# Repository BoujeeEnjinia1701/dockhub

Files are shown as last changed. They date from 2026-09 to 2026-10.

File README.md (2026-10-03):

# DockHub

     

**Area:** Smart Cities · **TRL:** 3 of 9 (proof of concept on paper) · **Value-engineering target:** about $1,200 USD (four-bay cabinet, two bays fitted) · **Difficulty:** 4 of 5

A street-side battery swap and charging station for SwapCell packs, serving e-bikes, cargo trikes and delivery riders with charged batteries in seconds.

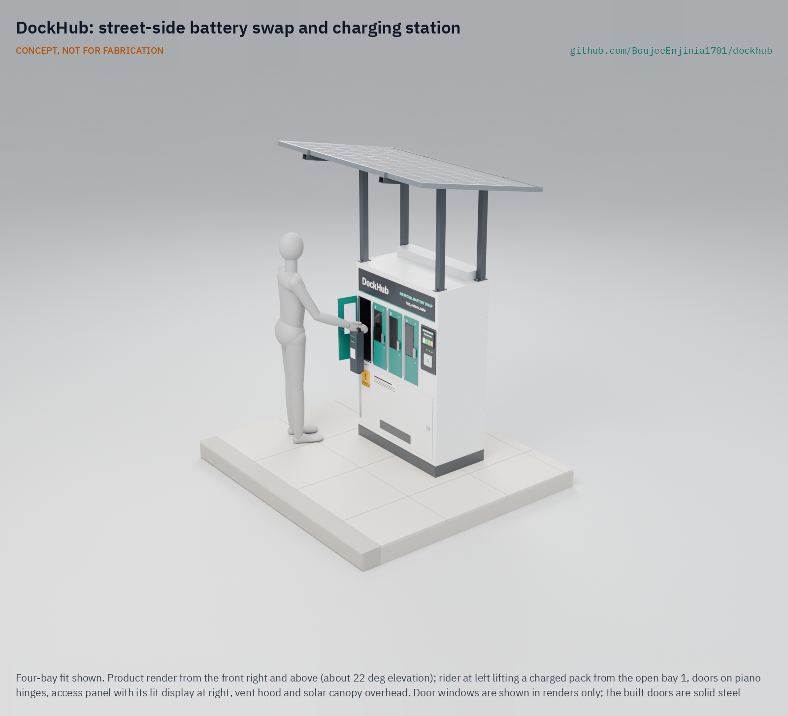
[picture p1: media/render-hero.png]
DockHub: street-side battery swap and charging station, product render


[Exploded render](media/render-exploded.png) · [Detail render](media/render-detail.png) · [Interactive 3D model](media/viewer.html) · [Concept blueprint (PDF)](media/concept-blueprint.pdf) · [General arrangement DKH-DWG-001 (PDF)](cad/drawings/DKH-DWG-001.pdf) · [Sizing note](docs/04-calcs/01-sizing.md) · [Prototype build plan](docs/05-build-plan.md) · [Design decisions](docs/06-design-decisions.md) · [Review note](docs/REVIEW.md)

## Concept rationale

Swapping moves charging out of homes and into a monitored steel cabinet, and turns hours at a socket into about 30 seconds at the curb. DockHub does this by putting four copies of the SwapCell wall dock into one sidewalk cabinet: each bay has its own cradle, certified charger and CAN check, and its own steel compartment that vents to the back and up, away from the rider. The cabinet adds only what a public site needs: access control, fire detection, a single-phase grid supply and a solar canopy that also shades the front.

It is open and garage-buildable because closed swap networks tie riders and small fleets to one operator's batteries. DockHub is folded sheet steel, off-the-shelf certified chargers and an ESP32, built to the open SwapCell interface, so a city, a rider cooperative or a courier firm can build, repair and inspect its own station and use packs from any SwapCell-compatible source.

## Burning platform

Most lithium battery fires in light vehicles start during charging, and much of that charging happens where people sleep. The US Consumer Product Safety Commission counted 227 micromobility battery incidents from 2019 to 2023, associated with 39 deaths and 181 injuries; 120 of them happened while charging ([Federal Register, 24 June 2026](https://www.federalregister.gov/documents/2026/06/24/2026-12749/safety-standard-for-lithium-ion-batteries-used-in-micromobility-products-and-electrical-systems-of)). New York City had 277 lithium-ion battery fires in 2024 ([FDNY](https://www.nyc.gov/site/fdny/news/03-25/fdny-commissioner-robert-s-tucker-significant-progress-the-battle-against-lithium-ion)), and London Fire Brigade attended a record 206 e-bike and e-scooter fires in 2025, an average of one every other day ([London Fire Brigade](https://www.london-fire.gov.uk/news/2026-news/january/record-number-of-e-bike-and-e-scooter-fires-across-london-in-2025-as-brigade-calls-for-regulation-to-be-introdu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)).

At the same time, the number of electric two- and three-wheelers keeps growing: India sold about 880,000 electric two-wheelers and more than 580,000 electric three-wheelers in 2023 ([IEA, Global EV Outlook 2024](https://www.iea.org/reports/global-ev-outlook-2024/trends-in-other-light-duty-electric-vehicles)). India's draft swapping policy notes that charging these vehicles "takes at least 3 to 4 hours" while a swap takes minutes ([NITI Aayog, 2022](https://www.niti.gov.in/sites/default/files/2022-04/20220420_Battery_Swapping_Policy_Draft_0.pdf)). For people paid per delivery or per trip, that time is lost income.

## Where it could be used

### By industry

| Industry | Use |
| --- | --- |
| App-based food and parcel delivery | Curbside swaps near restaurant clusters so riders never charge at home |
| Courier and cargo-bike logistics | Depot or loading-zone station for cargo trikes sharing one pack pool |
| Moto-taxi and informal transport | Swaps at taxi ranks and markets for light electric two- and three-wheelers |
| Shared micromobility | Battery exchange for shared e-bike and scooter fleets without vans collecting vehicles |
| Property and retail hosts | A safe charging offer for tenants or staff, instead of packs in corridors |
| Municipal fleets | Parks, parking and postal staff on e-bikes and cargo trikes |

### By country or region

| Country or region | Why it matters there |
| --- | --- |
| United States (New York City) | 268 lithium-ion battery fires and 18 deaths in 2023, 277 fires in 2024 ([FDNY](https://www.nyc.gov/site/fdny/news/03-25/fdny-commissioner-robert-s-tucker-significant-progress-the-battle-against-lithium-ion)); swap hubs for delivery workers already operate there ([Swobbee](https://www.swobbee.com/)) |
| United Kingdom (London) | Record 206 e-bike and e-scooter fires in 2025; every person killed in these fires since 2023 did not own the e-bike involved ([London Fire Brigade](https://www.london-fire.gov.uk/news/2026-news/january/record-number-of-e-bike-and-e-scooter-fires-across-london-in-2025-as-brigade-calls-for-regulation-to-be-introdu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)) |
| Australia (New South Wales) | 272 lithium-ion battery fires and 38 injuries in 2023, about five a week ([Fire and Rescue NSW](https://www.fire.nsw.gov.au/media/news/2024/20240315-fire-and-rescue-nsw-recording-lithium-ion-battery-fires-at-a-rate-of-five-a-week)) |
| India | The largest electric three-wheeler market, with more than 580,000 sold in 2023 ([IEA](https://www.iea.org/reports/global-ev-outlook-2024/trends-in-other-light-duty-electric-vehicles)); national policy favors interoperable swapping ([NITI Aayog](https://www.niti.gov.in/sites/default/files/2022-04/20220420_Battery_Swapping_Policy_Draft_0.pdf)) |
| East Africa (Rwanda and Kenya) | Moto-taxi swapping already runs at scale, with more than 20,000 swaps a day on one closed network ([Ampersand](https://www.ampersand.energy/)); an open station could serve smaller operators |
| Southeast Asia (Vietnam) | About 250,000 electric two-wheelers sold in 2023, most of the ASEAN total ([IEA](https://www.iea.org/reports/global-ev-outlook-2024/trends-in-other-light-duty-electric-vehicles)) |

## What sparked the idea

The starting point was New York City's public e-bike battery charging pilot. From February to August 2024 the city's Department of Transportation put swap cabinets and charging docks from three vendors on the street for 118 delivery workers, who made more than 12,000 battery swaps; at-home charging among participants fell by 35 percent, and no safety issues were reported at any pilot site ([NYC DOT, 21 November 2024](https://www.nyc.gov/html/dot/html/pr2024/report-e-bike-battery-change-pilot.shtml)). The pilot showed that a curbside cabinet can take charging out of homes. DockHub asks what the same cabinet looks like when it is built to an open pack interface (SwapCell), so that a city, a cooperative or a small fleet can build and run it without tying riders to one vendor's batteries.

## Problem

Light electric vehicle riders lose working time to charging, and charging lithium packs in homes and hostels causes fires. Commercial swap networks exist, but each one locks riders into its own batteries.

Full problem statement: [docs/01-problem.md](docs/01-problem.md)

## Concept

A street-side battery swap and charging station for SwapCell packs, serving e-bikes, cargo trikes and delivery riders with charged batteries in seconds. Four lockable bays at hand height each hold and charge one pack; a rider taps a card, returns a flat pack to the empty bay and takes a charged one in about 31 seconds. Because one bay is always empty, four bays run with three packs.

The TRL 3 sizing note (DKH-CAL-001) finds 1.2 h to charge a pack from 20 to 80 %, all 20 riders served on the design day (up to 36 swaps a day), 1.25 kW peak from one single-phase circuit with power-factor-corrected chargers, and a mass of about 217 kg for the two-bay prototype. The 400 W canopy supplies 9.3 % of the charging energy, and the SwapCell pack's 45 °C charge limit pauses charging when ambient air is above about 29 to 39 °C. Amish restated both targets on 2026-10-02: about 9 % solar, and full-rate charging up to about 30 °C ambient with daytime pauses accepted, so the first pilot goes where summer highs sit near that. The parts added to make the design buildable bring the estimated cost to $1,214, and the four M12 anchors and cast concrete pad chosen for the first pilot on private ground add $305, for $1,519 against the $1,200 value-engineering target. With the pad, the cabinet stays upright at a 30 m/s gust on paper; fire containment remains at risk.

Full design precis: [docs/02-concept.md](docs/02-concept.md) · Requirements: [docs/03-requirements.md](docs/03-requirements.md) · Calculations: [docs/04-calcs/01-sizing.md](docs/04-calcs/01-sizing.md) · Decisions: [docs/decisions/0001-trl2-review-decisions.md](docs/decisions/0001-trl2-review-decisions.md), [docs/decisions/0002-recommendations-accepted.md](docs/decisions/0002-recommendations-accepted.md), [docs/decisions/0003-design-for-construction.md](docs/decisions/0003-design-for-construction.md)

## Key components

- Galvanized steel cabinet, 1.0 x 0.5 m footprint, with four lockable SwapCell bays (interface v0.3) in separate steel compartments; the first prototype fits two
- Certified 54.6 V 5 A charger per bay with power factor correction, switched by the controller
- ESP32 dock controller with one CAN channel per bay and an LTE-M modem
- NFC access panel with display and status lights
- Heat and smoke detection, aerosol suppression and a rear vent plenum
- 400 W solar canopy with MPPT controller feeding bay 1, and a single-phase grid input with RCD protection
- Steel plinth held by four M12 wedge anchors to a 1,400 x 1,100 x 300 mm cast concrete pad; the canopy makes anchoring mandatory

The priced bill of materials is in [bom/bom.csv](bom/bom.csv). Value-engineering target for the four-bay cabinet with two bays fitted: $1,200 (a hypothetical control target, not a limit). Estimated cost of the constructable design: $1,519 ($319 over the target) on indicative prices, including $305 for the anchors and site pad; cost drivers and savings worth trying are in the [design decisions register](docs/06-design-decisions.md). All four bays fitted cost $1,743. A vermiculite bay floor tray is priced as a trial option for the propagation trial and is not in the total. SwapCell packs are not included. The parametric model is [cad/src/model.py](cad/src/model.py), with STEP and STL exports in `cad/step/` and `cad/stl/`.

## Building the prototype

The [prototype build plan](docs/05-build-plan.md) (DKH-BLD-001) shows how to make each of the cabinet's components and put them together in 22 steps, with a making sketch for every made part and a picture for every step. The cabinet is a shell of folded 1.5 mm galvanized panels joined with blind rivets on a welded channel plinth, with a roof frame of steel angle carrying the canopy posts. Making the concept buildable changed some details, such as the 150 mm door openings, the vent hood over the roof fans and the roof beams, all listed in [DKH-DDR-003](docs/decisions/0003-design-for-construction.md) for Amish's review. It is a plan: nothing has been built.

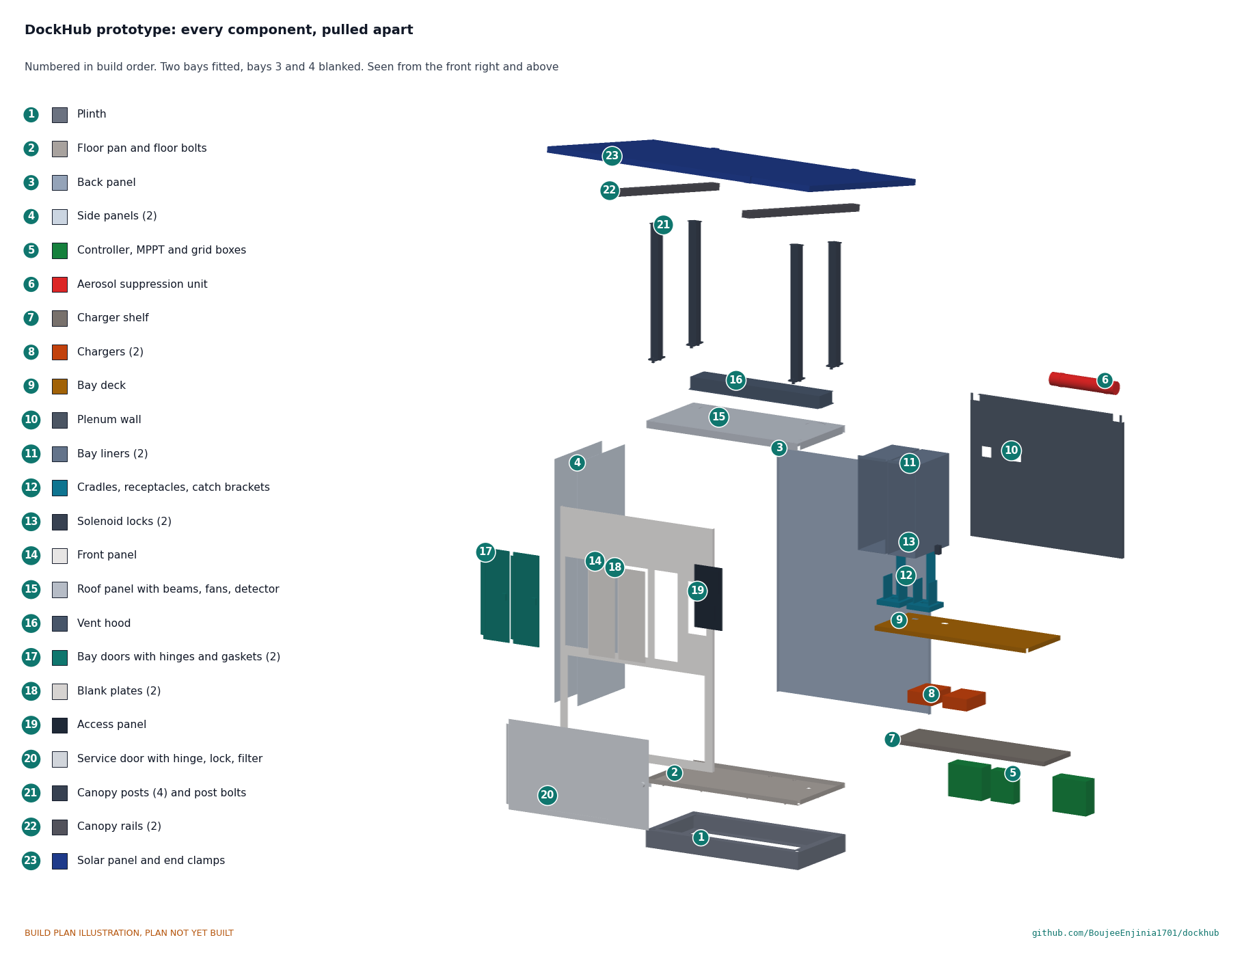
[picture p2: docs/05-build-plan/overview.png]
DockHub prototype: every component, pulled apart and numbered in build order


## Safety

> Lithium cells can overheat, vent and burn. DockHub holds up to four packs of about 468 Wh each beside a public walkway. Charge only packs that pass the SwapCell CAN check, keep faulted packs locked in their bay, and never leave a first build charging unattended. Mains wiring must be done or checked by a qualified electrician and follow local electrical code, with RCD (GFCI) protection. Fire detection and venting are in every bay, but fire containment is not yet proven. Anchor the cabinet to a concrete pad: in a 30 m/s gust the canopy lifts and tips it (DKH-CAL-001). Charging pauses in hot weather because the packs may not charge above 45 °C.

## Repository layout

| Folder | Contents |
| --- | --- |
| `docs/` | Problem, concept, requirements, calculations and design decisions |
| `cad/src/` | build123d Python source, the source of truth for all geometry |
| `cad/step/`, `cad/stl/` | Exported models for FreeCAD, other CAD tools and printing |
| `cad/drawings/` | 2D sketches and dimensioned drawings |
| `bom/` | Bill of materials |
| `electronics/` | KiCad schematics and PCB layouts |
| `firmware/` | Microcontroller code |
| `media/` | Renders, perspectives and photos |
| `build-log/` | Dated prototyping notes |

## Documentation

Controlled documents follow the portfolio [documentation standard](.kit/STANDARDS.md). Each carries a document ID (DKH-PRC-001 for the precis), a version and a revision history. Branded PDFs are built with `python .kit/render.py` and attached to GitHub Releases when a document is tagged, for example `DKH-PRC-001/v1.0`.

## Credits

Designed by Amish Chadha. See [CONTRIBUTORS.md](CONTRIBUTORS.md) for roles. To cite this design, use [CITATION.cff](CITATION.cff) (GitHub shows it as "Cite this repository").

AI assistance (Claude) was used to accelerate concept renders, prototype documentation and first-pass sizing calculations. Design direction and all decisions are Amish Chadha's, recorded in this repository's decision records (`docs/decisions/`).

## Licenses

- **Hardware** (CAD, drawings, BOM, electronics): [CERN-OHL-S v2](LICENSE)
- **Software** (firmware, scripts, notebooks): [MIT](LICENSE-SOFTWARE)

A project of the [Design Molecule](https://designmolecule.com) lab.

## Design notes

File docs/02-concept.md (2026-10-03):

---
doc_id: DKH-PRC-001
title: DockHub design precis
project: DockHub
doc_type: Design precis
version: "0.8"
status: Draft
date: '2026-10-02'
author: Amish Chadha
license: CERN-OHL-S-2.0
revisions:
- version: "0.1"
  date: '2026-09-25'
  author: Amish Chadha
  change: Initial scaffold
- version: "0.2"
  date: '2026-09-25'
  author: Amish Chadha
  change: Populate to TRL 2 (architecture, first-order numbers, safety, media)
- version: "0.3"
  date: '2026-09-25'
  author: Amish Chadha
  change: TRL 3. Record the TRL 2 review items adopted under Amish's 2026-09-25 instruction (DKH-DDR-001); SwapCell interface v0.3; numbers checked against DKH-CAL-001; media from the parametric model
- version: "0.4"
  date: '2026-09-25'
  author: Amish Chadha
  change: Recommendations accepted by Amish (DDR-002)
- version: "0.5"
  date: '2026-10-01'
  author: Amish Chadha
  change: Constructable design (DKH-DDR-003, Draft) and prototype build plan DKH-BLD-001; components, mass, cost and R16 status updated
- version: "0.6"
  date: '2026-10-01'
  author: Amish Chadha
  change: Budget treated as a value-engineering target
- version: "0.7"
  date: '2026-10-02'
  author: Amish Chadha
  change: "R6, R9, pack ownership, pilot partner, propagation test, suppression, siting and anonymous cards as decided on 2026-10-02 (DKH-DEC-001)"
- version: "0.8"
  date: '2026-10-02'
  author: Amish Chadha
  change: "Approved follow-ups carried into the design: anchors and site pad (BOM 17, 18; R15 met), vermiculite floor trial option (BOM 19), anonymous prepaid cards in the token list, flattest-pack solar sensitivity; numbers from DKH-CAL-001 v0.6"
---

# DockHub design precis

## Summary

DockHub is a sidewalk cabinet, 1.0 m wide and 0.5 m deep, with four lockable steel bays that each hold and charge one SwapCell pack. A rider taps a card or phone, returns a flat pack to the empty bay and takes a charged one from another, in about 31 seconds. Each bay is a copy of the SwapCell wall dock built to SwapCell interface v0.3: a cradle with the blind-mate receptacle and its 10 kΩ INTERLOCK coding resistor, a certified 54.6 V 5 A charger and a CAN channel that checks the pack before charging. Every bay is its own steel compartment venting to a rear plenum, so a pack fault is detected, cut off and ducted away from the user side. A 400 W solar canopy shades the front and feeds bay 1; the grid supplies the rest through one single-phase circuit.

The sizing note DKH-CAL-001 confirms the swap time, charge speed, throughput (with four bays), grid draw, reach heights and footprint. It also showed two requirements not met: the canopy supplies 9.3 % of the charging energy against the relaxed 10 % target (R6), and the pack's 45 °C charge limit stops charging whenever ambient air is above about 29 to 39 °C (R9). On 2026-10-02 Amish restated R6 as about 9 % and R9 as full-rate charging up to about 30 °C ambient, with daytime pauses accepted (DKH-DEC-001); R6 is now met on paper and R9 at risk. Making the design buildable (DKH-DDR-003) took the estimated cost to $1,214, and the anchors and cast site pad chosen for the first pilot on private ground add $305, so the two-bay prototype is estimated at $1,519 against the $1,200 value-engineering target (R16, $319 over). With the anchors and pad, anchoring (R15) is met on paper; fire containment (R8) remains at risk. Because a swap needs an empty bay, the four-bay station runs with three packs and the two-bay first prototype with one (DKH-REQ-001, DKH-DDR-001).

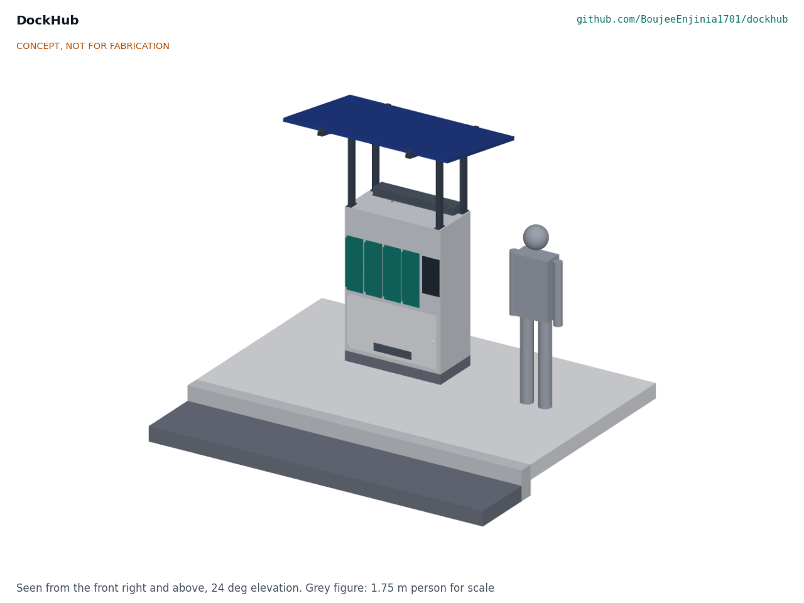
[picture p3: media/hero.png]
DockHub on a sidewalk


*Figure 1. DockHub on a sidewalk with a 1.75 m person for scale, four-bay fit with three packs and one empty bay. Rendered from the parametric model `cad/src/model.py`; concept, not for fabrication.*

## How it works

1. **Identify.** The rider taps an NFC card or phone on the access panel (BOM 7). The controller (6) checks the token against its local list, so the station works without a network connection. The list holds named tokens and anonymous prepaid cards sold by the partner, each card carrying a pack deposit and a number of prepaid swaps; an anonymous card is known to the station only by a hash of its identifier.
2. **Return.** The empty bay's door (2) unlocks. The rider places the flat pack connector down in the cradle (3) and closes the door. The receptacle mates ground first, then power and CAN, and the interlock last. The 10 kΩ coding resistor in the INTERLOCK loop wakes the pack, as SwapCell interface v0.3 requires (item W).
3. **Check.** The controller sends the SwapCell heartbeat as a dock (host type 1) on that bay's CAN channel. The pack reports its identity, limits, temperatures and state of health. A pack with a fault, a damage flag or a state of health below 70 % stays locked in and is flagged for a technician; the rider still gets a charged pack.
4. **Release.** The door of the fullest healthy pack at 80 % state of charge or more unlocks; the rider lifts it out by its handle and closes the door. That bay becomes the empty bay for the next rider. The controller logs the pair of pack IDs against the rider token.
5. **Charge.** When the pack's limits allow, the controller closes that bay's DC contactor and its charger (5) runs CC-CV to 54.6 V. Bay 1 charges from the solar panel (11) through the MPPT controller (13) whenever the panel offers 50 W or more, and from its AC charger otherwise.
6. **Watch.** A thermistor at every receptacle, the pack's own temperature reports and a heat and smoke detector (9) are read every second. On an alarm the bay contactor opens, fans (10) run, the bay door stays locked, a light and buzzer warn people to stand back and an alert goes out by LTE-M.

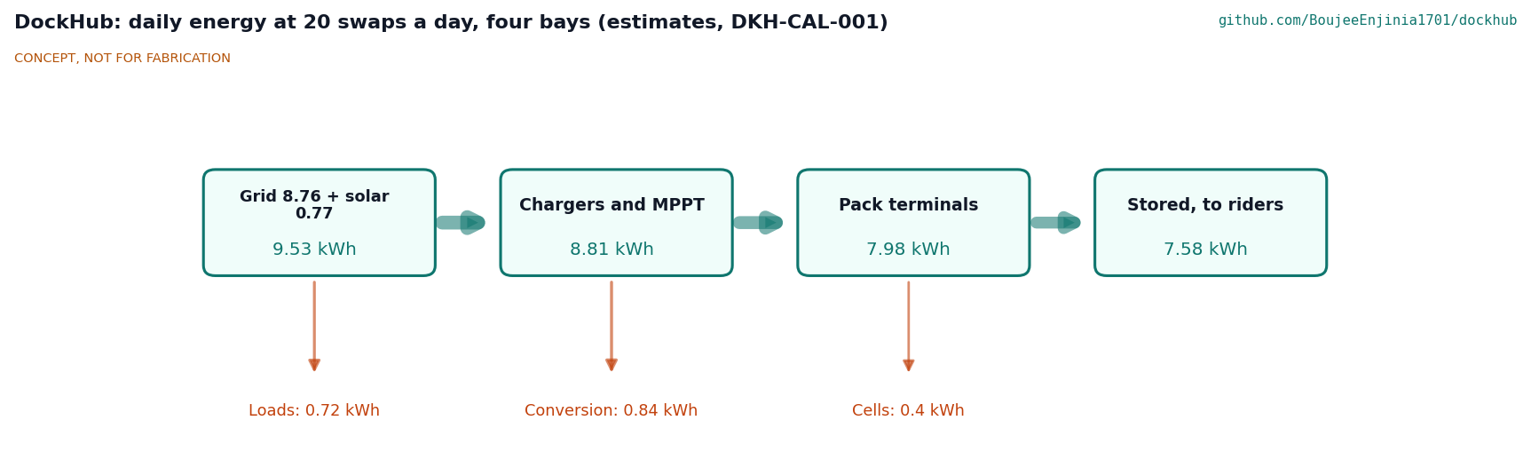
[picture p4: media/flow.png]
Daily energy flow


*Figure 2. Daily energy at the design duty case of 20 swaps a day with four bays. All values are estimates from DKH-CAL-001.*

## Main components

Table 1. Main components. Numbers match the exploded view (Figure 3) and `bom/bom.csv`.

| BOM | Component | Concept choice | Notes |
| --- | --- | --- | --- |
| 1 | Cabinet body | 1.5 mm galvanized steel panels with folded flanges, joined with blind rivets (laser-cut front panel, back, two sides, roof, floor pan), 1,000 x 500 x 1,400 mm on a 100 mm plinth; bay deck at 0.70 m and charger shelf below; roof frame of two 40 x 40 x 4 mm angle beams under the canopy posts | IP54 target; light powder coat; blank plates over unfitted bays |
| 2 | Bay doors (4; 2 in the first prototype) | 2 mm steel doors on stainless piano hinges over 150 x 510 mm openings, with EPDM gaskets, 12 V fail-secure solenoid locks and door switches | Locked unless the controller releases them |
| 3 | Bay compartments (4; 2 in the first prototype) | Steel liner 180 x 358 x 530 mm per bay with a vent port to the plenum; cradle printed with its SwapCell guide faces, folded catch bracket with class D latch catch, and receptacle with 10 kΩ INTERLOCK coding resistor; NTC at the receptacle | Mirrors the SwapCell wall dock; pack stands connector down, lid face toward the rider |
| 4 | SwapCell packs (reference) | Interface v0.3: 46.8 V nominal, about 468 Wh, 2.85 kg, 340 x 90 x 80 mm body, 393 mm overall | Three resident with four bays, one with two; priced in the SwapCell project |
| 5 | Chargers (4; 2 in the first prototype) | Certified 54.6 V 5 A CC-CV lithium-ion chargers, about 303 W input each, power factor 0.9 or better | No custom mains electronics |
| 6 | Dock controller | ESP32, four SPI CAN controllers (one channel per bay), DC contactors, current sensors, LTE-M modem, SD card | One channel per bay because every SwapCell pack answers as node 0 by default |
| 7 | Access panel | NFC reader at 0.90 to 0.99 m, display and per-bay status lights, in a column at 0.85 to 1.21 m | Beside bay 4 |
| 8 | Grid input and protection | RCBO (30 mA), a breaker per charger, surge protection and lockable isolator | Installed by a qualified electrician |
| 9 | Fire detection and suppression | Heat and smoke detector under the roof, condensed-aerosol unit strapped to the back panel at the plenum top | Aerosol can suppress flame but cannot stop a cell in runaway; vermiculite floors are tested against it (line 19) |
| 10 | Vent plenum and roof vent hood | Rear plenum 137 mm deep behind the bays, two 120 mm fans under the roof blowing through it into a vent hood with slots in its back face and a rain lip; filtered intake in the service door | Takes charger heat and any vented gas up and out at the back |
| 11 | Solar panel | 400 W monocrystalline, tilted 10 degrees, front top edge at 2.45 m, rear edge underside at 2.21 m | Shades the rider and the front of the cabinet |
| 12 | Canopy frame | Four 50 x 50 x 3 mm steel posts on welded base and cap plates, bolted through the roof into the roof beams; two 50 x 40 x 3 mm rails; four panel end clamps | Front posts see about 1.25 kN of uplift at a 30 m/s gust |
| 13 | MPPT controller | Programmable lithium profile at 54.6 V, output limited to 5 A, feeding bay 1 | Bay 1 keeps its AC charger as a fallback |
| 14 | Plinth and anchor frame | Welded 100 x 50 x 5 mm steel channel frame flush with the body (1,000 x 500 mm), floor bolted to it, with four M12 anchor holes and socket holes above them | Anchors and pad are lines 17 and 18 |
| 15 | Service door | 920 x 520 mm steel door on a piano hinge over the technical compartment, with a cam lock and a filtered intake slot | Technician access only |
| 17 | Anchors (site) | Four M12 x 160 mm stainless wedge anchors, 100 mm embedment, tamper-resistant nuts | 3.8 kN design tension each; not in the exploded view |
| 18 | Site pad | Cast reinforced concrete pad 1,400 x 1,100 x 300 mm, about 1,109 kg, top flush with the ground | For the first pilot on private ground; not in the exploded view |
| 19 | Vermiculite bay floor (trial option) | Stainless tray 175 x 168 x 20 mm of exfoliated vermiculite on each bay floor in front of the cradle | Propagation trial only; not fitted to the first prototype or counted in its cost |

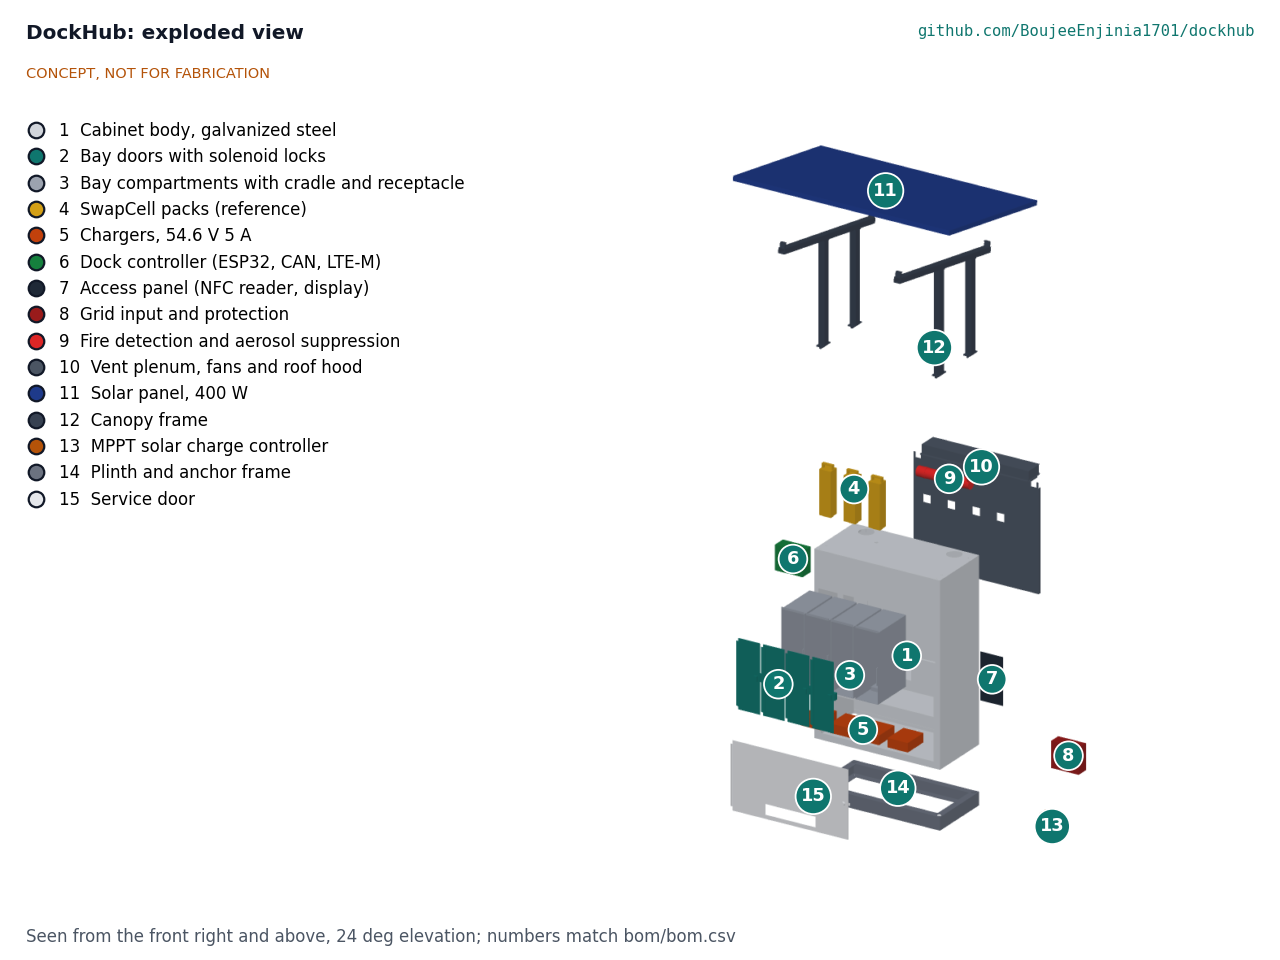
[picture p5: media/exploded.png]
Exploded view


*Figure 3. Exploded view of the four-bay fit with BOM numbers. Lines 16 to 19 (wiring and hardware, site anchors and pad, trial floor trays) are not shown.*

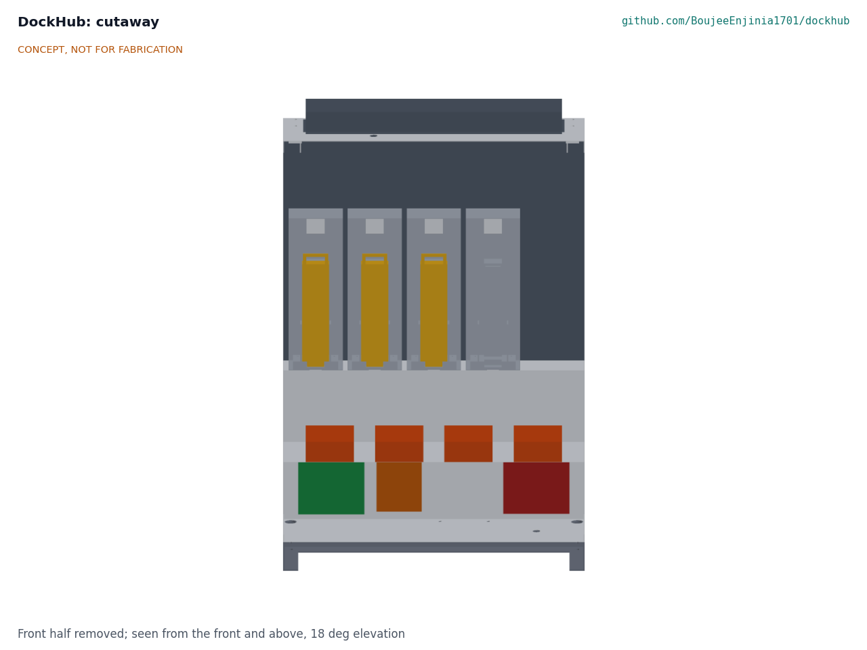
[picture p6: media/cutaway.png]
Cutaway


*Figure 4. Section through the cabinet from the front: three packs (4) in their bay compartments (3), with bay 4 empty for the next return, above the chargers (5), controller (6), MPPT controller (13) and grid input (8); the plenum (10) is behind the bays and the vent hood above.*

The parametric model `cad/src/model.py` models every component as it is made or bought (DKH-DDR-003) and checks that no two overlap and that every joint touches. It exports STEP and STL files to `cad/step/` and `cad/stl/`, and the general arrangement drawing DKH-DWG-001 (Rev P2, `cad/drawings/`) shows the first-prototype fit with bays 1 and 2 fitted and bays 3 and 4 blanked.

## Numbers

All values are estimates from DKH-CAL-001, printed by `docs/04-calcs/sizing.py`.

Table 2. Key numbers.

| Quantity | Value | Requirement |
| --- | --- | --- |
| Swap time | 31 s by task analysis | R1 met |
| Charge time per bay | 1.2 h (20 to 80 %), 2.3 h full; 1.3 h from a 15 % return to the 80 % release level | R3 met |
| Energy per swap | 398 Wh stored, 465 Wh from the grid, about $0.093 at $0.20/kWh | |
| Throughput ceiling | 36 swaps a day with four bays (three packs, released full); 12 with two bays | |
| Design day, 20 swaps | Four bays: 20 served, longest wait 4 min. Two bays: 9 served | R4 met by four bays |
| Daily energy at 20 swaps | 8.76 kWh from the grid (0.72 kWh cabinet loads), 0.77 kWh from the panel, 7.58 kWh stored in packs | |
| Solar share | 9.3 % of charging energy; 11.4 % if flat packs are routed to bay 1 in daylight, at the cost of one rider in 20; 16.1 % if the solar output is switched to the flattest pack (TRL 4 trial, not adopted) | R6 met (thin margin) against about 9 % |
| Peak grid draw | 1.25 kW with four chargers; 11.0 A at 120 V and 5.7 A at 230 V with power factor 0.95 | R5 met with power-factor-corrected chargers |
| Cabinet air at 45 °C ambient | about 49 °C (4.2 to 4.8 K rise with fans and sun on two walls) | |
| Charging ambient limit | Uninterrupted 5 A charging only below about 29 to 39 °C ambient; cold-soaked packs cannot start below about -1 °C | **R9 at risk** against full-rate charging up to about 30 °C |
| Fire response | Electronic detection latency 3.1 s; contactor opens in about 0.15 s | R7 not verifiable at TRL 3 |
| Mass | 217 kg for the two-bay prototype without packs; 247 kg for four bays with three packs; site pad about 1,109 kg | |
| Wind at a 30 m/s gust | 1,590 N uplift and 1.5 kN drag; 2.91 kN·m overturning against 0.53 kN·m self-weight; with the pad, factor 1.12 against tipping after safety factors | R15 met with four M12 anchors and the cast pad |
| Parts cost | $1,519 with two of four bays fitted, anchors and pad included ($1,214 without them); $1,743 with four | **R16 over the value-engineering target by $319** |

## Key design choices

Items 1 to 8 are the TRL 2 recommendations, decided by Amish on 2026-09-25: go with recommendation (DKH-DDR-001, DKH-DDR-002).

1. **One SwapCell dock per bay, in a shared cabinet.** Each bay reuses the SwapCell dock cradle, charger and handshake, so DockHub adds only the cabinet, access, safety and energy supply. One certified charger and one CAN channel per bay, rather than a shared charger matrix.
2. **Four bays in one row at hand height.** Keeps the footprint to 1.0 x 0.5 m and every handle within reach (0.73 to 1.10 m). The first prototype fits bays 1 and 2 to stay close to the value-engineering target; the cabinet is built for four.
3. **Separate steel compartment per bay with a rear plenum.** A venting pack's gas and flame go to the back and up through the roof fans and vent hood, not out of the door the user is standing at, and each pack is separated from its neighbors by two steel walls and an air gap.
4. **Doors stay locked during a fire alarm.** Keeps people from opening a bay with a pack in runaway; the fire service opens the cabinet with a key. The trade-off is that a rider cannot retrieve a returned pack during an alarm; a warning light and a sign explain why.
5. **Grid first, solar as a supplement.** The 400 W canopy stays as shade and supplement, and R6 is relaxed to 10 %. DKH-CAL-001 finds 9.3 %; on 2026-10-02 Amish restated R6 as about 9 % with normal routing, and switching the solar charger to the bay with the flattest pack is a TRL 4 controller change to try (DKH-DEC-001).
6. **Solar feeds one bay directly through an MPPT controller.** Avoids an inverter and keeps all mains parts certified. It is also why the solar share is low: bay 1 can use the sun only while it holds a pack that needs charge.
7. **Offline-first access with NFC tokens.** The station keeps a token list and a log and syncs over LTE-M when it can, with an optional phone app. Each 20 B token entry records a hash of the card identifier, whether it is a named token or an anonymous prepaid card, whether a pack deposit is held, the prepaid swaps left and an expiry date (anonymous cards decided by Amish, 2026-10-02). The cabinet is unchanged.
8. **Pack health gate.** Packs below 70 % state of health, with a fault record or outside the charge temperature window are held for a technician, using the SwapCell in-pack log.

Engineering proposals made at TRL 3, decided by Amish on 2026-09-25: go with recommendation (DKH-DDR-001 items 12 and 13, DKH-DDR-002): build to SwapCell interface v0.3; release packs at 80 % state of charge or more; specify chargers with a power factor of 0.9 or better; a plinth flush with the body.

## Relationship to other lab projects

- **SwapCell** (pack, interface v0.3, wall dock). DockHub builds to interface v0.3 and changes nothing in it: coded INTERLOCK receptacle (item W), dock host type 1, class D catch (item V). A multi-bay dock still needs a CAN channel per bay, because packs default to node 0 and a node number would have to change at every station. SwapCell's 45 °C charge limit is what sets DockHub's hot-weather shortfall (R9); any question about it goes to that project, not changed here.
- **TwinKit** could later collect DockHub's logs alongside other lab devices. That is a suggestion only and is not part of this concept.

## Safety

> **Safety:** DockHub stores and charges lithium-ion packs of about 468 Wh each (three in the four-bay station, briefly four during a swap) next to a public walkway, from mains power. A cell in thermal runaway vents flammable, toxic gas and can ignite its neighbors; a pack fire is hard to extinguish and can re-ignite hours later. Treat the cabinet as a fire hazard at every stage of building and testing.

- **Lithium cells.** Charge only packs that pass the CAN check; never force-charge a pack that does not answer. Hold damaged, wet or faulted packs in their bay, uncharged, until a technician removes them to a fireproof container. Build and test the first cabinet on a non-combustible surface, outdoors or in a fire-rated space, with a lithium-rated extinguisher and a sand bucket at hand, and never leave it charging unattended until the detection and shutdown chain has been tested.
- **Fire containment is unproven.** The per-bay compartments and plenum are a concept. Whether they stop one pack's runaway from spreading (R8) can only be shown by a propagation test, which is TRL 4 or later work and on hold. Condensed-aerosol suppression can knock down flame but does not cool cells in runaway.
- **Mains voltage.** The technical compartment holds 120 V or 230 V AC wiring. It must be installed or checked by a qualified electrician under local electrical code, with an RCD (GFCI), per-charger breakers, surge protection, a lockable isolator and bonding of all metal parts to protective earth. Keep mains and the 54.6 V DC side physically separated and labeled. Use chargers with a power factor of 0.9 or better, or the circuit can be overloaded (DKH-CAL-001 section 6).
- **DC contacts and faults.** Receptacle contacts are at up to 54.6 V DC and a pack can deliver about 500 A into a short. Contacts stay dead until the SwapCell coded interlock and a valid heartbeat enable the pack. Each bay's DC line needs a fuse rated for 60 V DC with at least 1 kA breaking capacity.
- **Heat.** A sunlit cabinet in hot weather takes packs above their 45 °C charge limit; the pack and controller must pause charging, and the station must not be relied on for charging in the hottest hours.
- **Public siting and wind.** Place the cabinet away from building entrances, exits and windows, with the vent hood slots venting away from people. The canopy lifts and tips the cabinet in a strong gust: anchor the plinth to the cast site pad (1,400 x 1,100 x 300 mm) with the four M12 wedge anchors, each rated for at least 3.8 kN design tension, and bolt the canopy posts through to the roof frame. Keep a clear pedestrian path beside the cabinet.
- **Pinch, lifting and sharp edges.** Fold or hem all sheet edges; door locks must not pinch fingers. Canopy edges above head height need rounded corners. The cabinet weighs about 217 kg empty: move it with lifting equipment, not by hand.

## Open questions

- Pack ownership model: a station-owned pool of packs exchanged one for one, as R10 assumes; to be confirmed in co-design. Decided by Amish, 2026-10-02 (DKH-DEC-001).
- First pilot site and partner: a delivery-worker group in a high-income city, New York City first, with Los Deliveristas Unidos (Workers Justice Project) as the first candidate partner to approach. Decided by Amish, 2026-10-02 (DKH-DEC-001).
- R6: restated as about 9 % with normal routing; flattest-pack solar switching to be tried at TRL 4 as a controller change. Decided by Amish, 2026-10-02 (DKH-DEC-001).
- R9: keep the pack's 45 °C charge limit and accept daytime pauses; R9 restated as full-rate charging up to about 30 °C ambient, with the cold-soak limit near -1 °C stated; active cooling only for a hot-climate site. Decided by Amish, 2026-10-02 (DKH-DEC-001).
- The two-bay first prototype holds only one pack and cannot run the duty case. Is that acceptable for a first build, given R16?
- Propagation test: a later version aims at a UL 9540A unit-level propagation test, with a heater-triggered runaway in one bay at an outdoor test site first, before paying an accredited lab. Decided by Amish, 2026-10-02 (DKH-DEC-001); whether a workshop-built cabinet can pass it is what the self-run trial will show.
- Fire suppression: keep the condensed-aerosol unit for the first prototype and test vermiculite-filled bay floors as a variant in the propagation trial; choose on the result. Decided by Amish, 2026-10-02 (DKH-DEC-001).
- Siting: the first pilot is on private property with an existing single-phase circuit (the partner's premises or a willing business frontage), not on a public sidewalk; a city sidewalk permit is sought only for a second site. Decided by Amish, 2026-10-02 (DKH-DEC-001).
- Riders who do not want to share identity: anonymous prepaid NFC cards sold by the partner, each carrying a pack deposit, alongside named tokens. Decided by Amish, 2026-10-02 (DKH-DEC-001).

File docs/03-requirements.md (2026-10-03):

---
doc_id: DKH-REQ-001
title: DockHub requirements
project: DockHub
doc_type: Requirements
version: "0.8"
status: Draft
date: '2026-10-02'
author: Amish Chadha
license: CERN-OHL-S-2.0
revisions:
- version: "0.1"
  date: '2026-09-25'
  author: Amish Chadha
  change: Initial scaffold
- version: "0.2"
  date: '2026-09-25'
  author: Amish Chadha
  change: First measurable requirements for TRL 2
- version: "0.3"
  date: '2026-09-25'
  author: Amish Chadha
  change: TRL 3. R6 relaxed to 10 % and R16 redefined to the two-bay fit (DKH-DDR-001); R2 to SwapCell interface v0.3; status from DKH-CAL-001
- version: "0.4"
  date: '2026-09-25'
  author: Amish Chadha
  change: Recommendations accepted by Amish (DDR-002)
- version: "0.5"
  date: '2026-10-01'
  author: Amish Chadha
  change: Status from DKH-CAL-001 v0.3 after the constructable design (DKH-DDR-003); R16 not met
- version: "0.6"
  date: '2026-10-01'
  author: Amish Chadha
  change: Budget treated as a value-engineering target
- version: "0.7"
  date: '2026-10-02'
  author: Amish Chadha
  change: "R6 restated as about 9 % and R9 as full-rate charging up to about 30 °C ambient (DKH-DEC-001); status updated"
- version: "0.8"
  date: '2026-10-02'
  author: Amish Chadha
  change: "Status from DKH-CAL-001 v0.6 after the approved follow-ups: R15 met with the anchors and site pad chosen; R16 USD 1,519 with them; R12 token list with anonymous prepaid cards"
---

# DockHub requirements

These requirements are checked by calculation in DKH-CAL-001 (TRL 3). They are not yet validated with riders, hosts or a city and will be revised after co-design sessions (see DKH-PRB-001). On 2026-09-25 Amish accepted the review recommendations (DKH-DDR-001, DKH-DDR-002): R6 is relaxed from 20 % to 10 %, R16 covers the four-bay cabinet with two bays fitted, and R2 cites SwapCell interface v0.3 (DKH-DDR-001 item 12). These are decided. On 2026-10-02 Amish restated R6 as about 9 % and R9 as full-rate charging up to about 30 °C ambient (DKH-DEC-001). Every other target remains as proposed at TRL 2 and will be revised after co-design.

On paper, 11 of 16 requirements are met. R16 is over its value-engineering target; R8 and R9 are at risk; R7 and R14 cannot be verified until hardware exists.

The **design duty case** used throughout is 20 swaps a day, each returning a SwapCell pack at about 15 % state of charge, in a street location with 4.5 peak sun hours and ambient air between -10 and 45 °C. Because a swap needs an empty bay, a station with *n* bays holds *n* - 1 packs.

Table 1. Requirements. Status is from DKH-CAL-001.

| ID | Requirement | Target | Verification | Status at TRL 3 (DKH-CAL-001) |
| --- | --- | --- | --- | --- |
| R1 | Fast swap | 60 s or less from tapping the reader to closing the second door, for a rider familiar with the station | Task analysis; later timed trials with riders | Met (31 s) |
| R2 | SwapCell compatibility | Every bay builds to SwapCell interface v0.3: envelope, guide faces, blind-mate receptacle with the 10 kΩ INTERLOCK coding resistor, class D catch, CAN heartbeat and message set; no change to the interface | Interface review with the SwapCell project | Met by design review; one CAN channel per bay |
| R3 | Charge speed | 20 to 80 % in 1.5 h or less; full charge in 2.5 h or less, per bay, at 25 °C | Charge profile calculation | Met (1.2 h and 2.3 h) |
| R4 | Throughput | 20 or more swaps a day from 4 bays at the design duty case | Day model with a demand profile | Met by the four-bay fit (20 of 20 served, longest wait 4 min; ceiling 36 a day). The two-bay first prototype serves 9 of 20 |
| R5 | Grid supply | One single-phase branch circuit (120 V 15 A or 230 V 10 A); peak draw 1.5 kW or less | Load calculation | Met (1.25 kW; 11.0 A at 120 V) with chargers of power factor 0.9 or better |
| R6 | Solar contribution | Canopy solar supplies about 9 % of daily charging energy at the design duty case, with normal routing (restated on 2026-10-02, DKH-DEC-001; relaxed from 20 % to 10 % by DKH-DDR-001) | Day model | Met on paper, thin margin (9.3 %; 11.4 % if flat packs are routed to bay 1 in daylight, which turns one rider in 20 away, so normal routing is kept; 16.1 % if the solar output is later switched to the flattest pack, a TRL 4 trial) |
| R7 | Fire detection and response | Detect a pack or bay over 60 °C, or smoke, within 10 s; open that bay's charge contactor within 1 s of detection; sound a local alarm and send a remote alert; vent gas to the rear roof louver, away from the user side | Latency budget; later bench test with a heat source | Not verifiable at TRL 3 (electronic latency 3.1 s, contactor 0.15 s) |
| R8 | Fire containment | A thermal runaway in one bay does not spread to a neighboring bay or pack for 30 min or more, and flame does not leave the cabinet front | Later propagation test by an accredited lab | **At risk**; not verifiable at TRL 3 |
| R9 | Climate | Enclosure IP54 or better; operate (store and swap) at -10 to 45 °C ambient; full-rate charging up to about 30 °C ambient, with daytime pauses accepted above it and no charging start for cold-soaked packs below about -1 °C; never charge a pack outside the pack's reported charge temperature window (restated on 2026-10-02, DKH-DEC-001) | Thermal calculation; later chamber test | **At risk**: uninterrupted charging needs ambient below about 29 to 39 °C (pack charge limit 45 °C), so the warmest bay may pause just under 30 °C; cold-soaked packs cannot start below about -1 °C, as now stated |
| R10 | Security | 1.5 mm or thicker steel; fail-secure bay locks; cabinet anchored to its pad with tamper-resistant fixings; a pack is released only against a valid token and a returned pack | Design review | Met by design review |
| R11 | Accessibility and use | All operable parts (reader, buttons, bay handles) 0.38 to 1.22 m (15 to 48 in) above the ground; status shown by light and symbol as well as text; usable with gloves and at night | Model check; later user trials | Met (0.73 to 1.10 m) |
| R12 | Privacy and data | No cameras or microphones; logs hold pack ID, bay, time, energy and state of health, with the rider as an opaque token; operates offline for 24 h or more and syncs later | Design review | Met by design review (token list of 200 kB, including anonymous prepaid cards with a pack deposit) |
| R13 | Sidewalk footprint | Cabinet footprint 1.0 x 0.6 m or less; canopy underside 2.1 m or more above the sidewalk | Model check | Met (1.0 x 0.5 m with a flush plinth; lowest canopy point over the sidewalk 2.17 m) |
| R14 | Maintainability | Any charger, lock, bay cradle or controller replaced in 15 min or less by one technician with hand tools, through the service door | Design review; later timed trial | Not verifiable at TRL 3 |
| R15 | Wind and anchoring | Stays upright and intact at a 30 m/s gust with the canopy fitted | Wind load calculation | Met on paper: four M12 stainless wedge anchors (3.8 kN design tension each) into a 1,400 x 1,100 x 300 mm cast pad of about 1,109 kg; equilibrium factor 1.12 at a 30 m/s gust. The anchor rating is confirmed from the maker's data when bought |
| R16 | Cost | Parts 1,200 USD or less for the four-bay cabinet with two bays fitted (first prototype), SwapCell packs excluded (redefined, DKH-DDR-001) | Priced BOM (`bom/bom.csv`) | **Over the value-engineering target by $319** ($1,519 against $1,200: $1,214 for the buildable cabinet, DKH-DDR-003, plus $305 for the anchors and site pad chosen on 2026-10-02; $1,743 with all four bays fitted) |

## Assumptions

- SwapCell pack (interface v0.3): 46.8 V nominal, about 468 Wh, 2.85 kg, charge on a certified 54.6 V 5 A charger in 2.3 h to full and 1.2 h for 20 to 80 %, charge window 0 to 45 °C (SWC-PRC-001 v0.3, SWC-CAL-001).
- Charger efficiency about 90 %, cell charge efficiency about 95 %, cabinet auxiliary load about 30 W on average and 40 W peak.
- 400 W panel, 4.5 peak sun hours, 0.8 derate, 96 % MPPT, feeding bay 1 only.
- Packs are released at 80 % state of charge or more, fullest first; riders arrive with a lunch and a dinner peak and leave after waiting 15 min (DKH-CAL-001 Table 1).
- Delivery riders cover roughly 60 to 100 km a day at about 10 Wh/km. This is an assumption to check with riders; it implies 1 to 2 swaps per rider per shift.
- Accessibility reach range from the US ADA forward reach limits (15 to 48 in); local rules may differ.

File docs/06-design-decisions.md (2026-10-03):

---
doc_id: DKH-DEC-001
title: DockHub design decisions register
project: DockHub
doc_type: Design decisions register
version: "0.4"
status: Draft
date: '2026-10-02'
author: Amish Chadha
license: CERN-OHL-S-2.0
revisions:
  - version: "0.1"
    date: '2026-10-01'
    author: Amish Chadha
    change: Register opened with the open decisions from the review note, the decision records and the build plan work
  - version: "0.2"
    date: '2026-10-01'
    author: Amish Chadha
    change: Budget treated as a value-engineering target
  - version: "0.3"
    date: '2026-10-02'
    author: Amish Chadha
    change: "Amish approved the recommendations for open decisions 1 to 13 (DKH-DDR-003 accepted); moved to decisions made"
  - version: "0.4"
    date: '2026-10-02'
    author: Amish Chadha
    change: "Approved follow-ups carried out: anchors and pad chosen (To confirm item 9 now the anchor rating only); value engineering restated with them"
---

# DockHub design decisions register

Every design decision still to be made, and every decision made, in one place. Each decision is argued in full in its decision record under `docs/decisions/`; this register is the index Amish works from. The build plan (`docs/05-build-plan.md`) describes the design as it stands and does not list open decisions.

## Open decisions

None. All open decisions were decided on 2026-10-02.

## To confirm when parts are bought

| # | What to confirm | Why it matters | Source |
| --- | --- | --- | --- |
| 1 | Charger footprint and fixing holes, and that its power factor is 0.9 or better | The shelf holes are marked from the charger; R5 holds only with power-factor-corrected chargers | DKH-CAL-001 section 6; BOM line 5 |
| 2 | Controller, MPPT and grid box sizes (no larger than 220 x 100 x 190, 150 x 70 x 180 and 220 x 92 x 200 mm) | They must fit between the floor flange and the shelf flange on the back panel | DKH-DDR-003, P9 |
| 3 | Solenoid lock size (about 30 x 30 x 50 mm) and bolt throw | The tongue position on the door is set from it | DKH-DDR-003, P6 |
| 4 | SwapCell v0.3 receptacle flange and fixing | The cradle's 72 x 50 x 9 mm pocket and its two M3 inserts are set from it | DKH-DDR-003, P7 |
| 5 | Fans 120 x 120 x 25 mm with corner holes on a 105 mm square | The roof holes and spacer positions are set from them | DKH-DDR-003, P5 |
| 6 | Aerosol unit size (about 76 x 420 mm) and its straps | Its position under the roof line, clear of the fans and beams | DKH-DDR-003, P9 |
| 7 | Solar panel size, frame depth (35 mm) and that the maker allows end clamps | The rail length and clamps are set from it | DKH-DDR-003, P3 |
| 8 | A printable flame-retardant filament rated UL 94 V-0 | The cradle material | DKH-DDR-003, P7 |
| 9 | The chosen M12 stainless wedge anchors (BOM line 17) have an approval giving a design tension resistance of at least 3.8 kN at 100 mm embedment in C25/30 concrete, 225 mm from the pad edge | R15 is met on paper with the anchors and the cast pad (BOM line 18) chosen on 2026-10-02; the anchor rating is the remaining check | DKH-CAL-001 section 11 |

## Value engineering

Value-engineering target: USD 1,200. Estimated cost of the constructable design: USD 1,519 (USD 319 over the target). The target is a hypothetical control target, not a limit, for the four-bay cabinet with two bays fitted and SwapCell packs excluded. The estimate now includes the anchors and cast site pad chosen on 2026-10-02 (lines 17 and 18, USD 305); without them it is USD 1,214. All four bays fitted cost an estimated USD 1,743; each further bay adds USD 112. The vermiculite floor tray (line 19, about USD 11 a bay) is a trial option and is not in the estimate.

Main cost drivers: the site pad (line 18, USD 265: 28 bags of premixed concrete, mesh, formwork and gravel), then the parts added to make the design buildable, which took the estimate from USD 1,199 to USD 1,214 (canopy end clamps, post plates and bolts, line 12, USD 60 to USD 70; service door hinge, line 15, USD 30 to USD 35), and the anchors (line 17, USD 40). All prices are indicative.

Savings worth trying: using the host's own slab instead of the cast pad where an engineer confirms it does the same job (up to USD 265); ready-mixed concrete instead of bags if the supplier delivers a small load; recovering the USD 14 of construction parts at supplier selection.

## Decisions made

| Date | Decision | Decided by | Record |
| --- | --- | --- | --- |
| 2026-09-25 | TRL 2 review items with a recommendation: four-bay cabinet with bays 1 and 2 fitted and a $1,200 value-engineering target (`budget_usd`) for that fit; 400 W canopy kept and R6 relaxed to 10 %; four bays in one row; one charger and CAN channel per bay; steel compartment per bay with a rear plenum; doors locked during a fire alarm; MPPT to bay 1; offline-first NFC access; 70 % health gate | Amish: "i accept all your recommendations, go with them across all repos." | DKH-DDR-001, DKH-DDR-002 |
| 2026-09-25 | TRL 3 engineering proposals: build to SwapCell interface v0.3; release packs at 80 % state of charge or more; chargers with a power factor of 0.9 or better; plinth flush with the body; 15 min rider patience and the demand profile of DKH-CAL-001; two-bay first prototype that cannot run the duty case | Amish, same instruction | DKH-DDR-001 items 12 and 13, DKH-DDR-002 |
| 2026-09-30 | Make each design physically buildable while drawing the build plan, recording every change | Amish: "If you are realising that the design cannot be built as per concept - fix the design assumptions to match and be physically feasible as you draw the illustrations." The resulting changes were accepted on 2026-10-02 (below) | DKH-DDR-003 |
| 2026-09-30 | Outstanding decisions are kept in this register, not in the build plan | Amish: "don't log outstanding decisions in this build plan - that is not the place for it." | STANDARDS section 18 |
| 2026-10-02 | Design for construction accepted: the changes P1 to P12 and their knock-on changes, as made | Amish: "i approve your recommendations for all 555 open decisions." | DKH-DDR-003, Table 1 |
| 2026-10-02 | Bay door hinges: stainless piano hinges with the pin ends peened over (option a) for the prototype; reviewed after the first site visit | Amish: "i approve your recommendations for all 555 open decisions." | DKH-DDR-003, A2 |
| 2026-10-02 | R6 restated as about 9 % of charging energy, with normal routing kept; switching the solar charger to whichever bay holds the flattest pack is to be tried as a TRL 4 controller change, not a cabinet change | Amish: "i approve your recommendations for all 555 open decisions." | DKH-DDR-002, Table 2 |
| 2026-10-02 | R9: keep the pack's 45 °C charge limit and accept daytime charging pauses; R9's charging range restated as full-rate charging up to about 30 °C ambient, with the cold-soak limit near -1 °C stated; the first pilot site is chosen with summer highs near that; active cooling revisited only for a hot-climate site | Amish: "i approve your recommendations for all 555 open decisions." | DKH-DDR-002, Table 2 |
| 2026-10-02 | Pack ownership: a station-owned pool of packs exchanged one for one, as the concept and R10 assume; to be confirmed in co-design | Amish: "i approve your recommendations for all 555 open decisions." | DKH-DDR-001 item 10 |
| 2026-10-02 | First pilot partner: a delivery-worker group in a high-income city, with New York City first and Los Deliveristas Unidos (Workers Justice Project) as the first candidate partner to approach | Amish: "i approve your recommendations for all 555 open decisions." | DKH-DDR-001 item 11 |
| 2026-10-02 | Propagation test for R8: a later version aims at a UL 9540A unit-level propagation test, with a heater-triggered runaway in one bay at an outdoor test site first, before paying an accredited lab | Amish: "i approve your recommendations for all 555 open decisions." | DKH-PRC-001, Open questions |
| 2026-10-02 | Fire suppression: keep the condensed-aerosol unit for the first prototype and test vermiculite-filled bay floors as a variant in the propagation trial; choose on the result | Amish: "i approve your recommendations for all 555 open decisions." | DKH-PRC-001, Open questions |
| 2026-10-02 | Siting: the first pilot on private property with an existing single-phase circuit (the partner's own premises or a willing business frontage), not on a public sidewalk; a city sidewalk permit is sought only for a second site | Amish: "i approve your recommendations for all 555 open decisions." | DKH-PRC-001, Open questions |
| 2026-10-02 | Riders who do not want to share identity: anonymous prepaid NFC cards sold by the partner, each carrying a pack deposit, alongside named tokens | Amish: "i approve your recommendations for all 555 open decisions." | DKH-PRC-001, Open questions |
| 2026-10-02 | Product renders: solid steel doors in the build; the clear windows are shown in the renders only | Amish: "i approve your recommendations for all 555 open decisions." | Review note, 2026-09-26, item 1 |
| 2026-10-02 | Product renders: scene state, header sign and markings accepted as render choices; renders captioned 'four-bay fit shown'; sign wording settled with branding | Amish: "i approve your recommendations for all 555 open decisions." | Review note, 2026-09-26, items 2, 3 and 5 |
| 2026-10-02 | Re-render the photoreal renders, card and social preview on Amish's Mac to the constructable design, now that decisions 1 and 2 are made | Amish: "i approve your recommendations for all 555 open decisions." | DKH-DDR-003, Consequences |

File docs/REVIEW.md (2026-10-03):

# Review note: DockHub

## Session 2026-10-02: Photoreal renders redone on the constructable design

Amish, 2026-10-02: "Photoreal renders are out of date in most repos ... COMPLETE THESE". Rendered with Blender Cycles on Amish's Mac (batch F1) from the scenes exported from `cad/src/product_model.py`, captioned with `.kit/photo_caption.py`; `media/card.png` and `media/social-preview.png` regenerated with `.kit/cards.py`. Each raw render was looked at once. No commit or push; `trl` unchanged.

- Views: `media/render-hero.png`, `media/render-exploded.png`, `media/render-detail.png`.
- Re-renders: none.
- Appearance deviations already logged (2026-09-26 session and decision 12, Proposed, awaiting Amish): clear windows in the bay doors (renders only; the caption says the built doors are solid steel); bay 1 open with its pack in the rider's hand; header sign, bay numbers, warning label and information plate; four-bay fit shown; the paved street setting. The louver rain hood and post base plates are now in `model.py`, so they are no longer deviations. Sign wording still to be settled by Amish.
- `python3 .kit/image_qc.py`: 5 images, 0 problems. `python3 .kit/render.py --check`: no FAIL, no storefront warning.
- The "Stale media" note of the 2026-10-01 session is removed; this work resolves it.

## Session 2026-10-02: approved follow-ups carried out

Amish, 2026-10-02: "497 follow-up actions that need CAD, drawing, picture, BOM or calculation work ... APPROVED CHANGES, COMPLETE THESE" and "Photoreal renders are out of date in most repos ... COMPLETE THESE". The nine follow-ups listed in the session below were worked through; no hardware was built or bought and `trl` stays 3.

### Follow-ups

1. Decision 3, solar switched to the flattest pack: **done as far as TRL 3 allows.** `sizing.py` now runs the rule as a sensitivity (not adopted): solar share 16.1 % with all 20 riders served, against 9.3 % with normal routing. The controller change itself is TRL 4 work; R6 is rerun on it if it is adopted.
2. Decision 4, R9 limits: **done.** DKH-CAL-001 section 7 states the restated limits (full rate up to about 30 °C, no start for cold-soaked packs below about -1 °C, calculated -1.1 °C).
3. Decision 7, self-run propagation trial plan: **not done.** A test plan is TRL 4 work and the portfolio is capped at TRL 3 (CLAUDE.md section 1). The trial variant it needs (item 4) is ready. Recommendation for TRL 4: plan the heater-triggered trial with plain and vermiculite floors side by side.
4. Decision 8, vermiculite floor variant: **done.** `build_components(variant="vermiculite")` adds a 175 x 168 x 20 mm stainless tray of vermiculite in front of each cradle (fit check clean, 3 mm to the cradle, rim 10.5 mm below the pack connector face); STEP `cad/step/dockhub-bay-vermiculite.step`; making sketch DKH-DWG-119; BOM line 19 at USD 11 a bay, quantity 0 (trial option, not in the total).
5. Decision 9, anchors and pad: **done.** Four M12 x 160 stainless wedge anchors at 100 mm embedment (BOM line 17, USD 40) into a cast reinforced pad 1,400 x 1,100 x 300 mm, about 1,109 kg (line 18, USD 265), chosen to work on any private host ground. With the cabinet the pad gives an equilibrium factor of 1.12 at a 30 m/s gust (0.9 on weight, 1.5 on wind). Modelled with `site=True` (STEP `cad/step/dockhub-site-pad.step`), making sketch DKH-DWG-120, build plan section 9 and safety stop S7. **Found while modelling the anchor nuts:** the plinth's top flange covered the anchor holes, so the socket path of DDR-003 P10 was blocked; 32 mm socket holes were added in the top flange and `model.py --check` now checks the socket path (clear).
6. Decision 10, anonymous prepaid NFC cards: **done.** Token entry restated (20 B: card identifier hash, type, deposit held, prepaid swaps left, expiry, flags) in DKH-PRC-001 and DKH-CAL-001 section 9; token list 160 to 200 kB. No cabinet change.
7. Decision 12, caption and sign: **caption done**: every view note in `cad/src/product_model.py` starts "Four-bay fit shown" and says the door windows are in renders only. **Sign wording not settled**: the render keeps "DockHub / SWAPCELL BATTERY SWAP / tap, return, take"; the final wording is for Amish with branding.
8. Decision 13, re-render to the constructable design: **scenes ready, renders not made here.** `cad/src/product_model.py` rebuilt from `cad/src/model.py` (piano hinges, 172 mm doors over 150 mm openings, vent hood with rear slots, square roof fans, roof beams, post base and cap plates, rails, end clamps, service door with intake slot; side intake slots and the louver block removed). Scenes exported to `/home/claude/renders/dockhub` (hero, exploded, detail). `media/render-*.png`, `media/card.png` and `media/social-preview.png` are made on Amish's Mac next.
9. Decision 6, approach Los Deliveristas Unidos: **not done.** Contacting a partner is Amish's action; nothing is agreed.

### Requirement status changes (DKH-CAL-001 v0.6)

- R6: not met to **met (thin margin)** in the calculation, against the restated target of about 9 % (9.3 %).
- R9: not met to **at risk** in the calculation, against the restated target (warmest bay may pause just under 30 °C).
- R15: at risk to **met on paper** (anchors and pad chosen; anchor rating to confirm from the maker's approval data).
- R16: still over the target, now by USD 319 (was USD 14), because the anchors and pad are now in the BOM.
- Counts: 11 met, 2 at risk (R8, R9), 2 not verifiable (R7, R14), 1 over its value-engineering target (R16).

### Cost and mass

Value-engineering target: USD 1,200. Estimated cost of the constructable design: USD 1,519 (USD 319 over the target); USD 1,214 without the anchors and pad; USD 1,743 with four bays. `budget_usd` unchanged. Mass unchanged: 217 kg (two-bay prototype, no packs), 247 kg (four bays, three packs); the site pad adds about 1,109 kg.

### Documents changed

- `cad/src/model.py` (variant and site options, plinth socket holes, socket access check, new clearances); STEP and STL regenerated, two new: `dockhub-bay-vermiculite`, `dockhub-site-pad`. Fit check: 0 overlaps in the two-bay, four-bay, vermiculite and site configurations; all joints touch.
- `bom/bom.csv` (lines 9 and 14 notes, new lines 17, 18, 19), `bom/bom-notes.md`.
- `docs/04-calcs/sizing.py` and `results.csv`; DKH-CAL-001 v0.6; DKH-REQ-001 v0.8; DKH-PRC-001 v0.8; DKH-BLD-001 v0.4; DKH-DEC-001 v0.4 (value engineering, To confirm item 9); DKH-DDR-003 v0.4 (consequences); `README.md`.
- Drawings: DKH-DWG-001 Rev P3; DKH-DWG-101 Rev P2; new DKH-DWG-119 and DKH-DWG-120 (P1); DKH-DWG-102 regenerated (no change of revision).
- Pictures: `docs/05-build-plan/overview.png`, `step-01.png`, `joint-01.png`; concept media (hero, blueprint DKH-DWG-010 Rev P2, exploded, cutaway, flow, `model.glb`, `viewer.html`).
- `cad/src/product_model.py`, `cad/src/build_plan_media.py`, `cad/src/sheets.py`, `cad/src/concept_media.py`.

### Proposed, awaiting Amish

- Render context: the renders keep the paved street setting although the first pilot is on private ground. Recommendation: keep it as the product image; option: a private frontage scene.
- The cast pad is the main cost driver (USD 265). Recommendation: keep it in the estimate; drop it only where an engineer confirms the host's own slab does the job.

### Cross-repo actions

None. No follow-up for this repo needs work in another repo.

### Safety

The site pad and anchors add work at the site: excavation, about 1.1 t of concrete and drilling into concrete (dust: wear a mask and eye protection). Safety stop S7 now names the pad, its 7 day cure and the anchor torque. The vermiculite tray is for the propagation trial only. Earlier hazards are unchanged.

### Recommended next step

Amish to render the three views on the Mac and settle the sign wording; at TRL 4, plan the self-run propagation trial with plain and vermiculite floors and try flattest-pack solar switching.

## Session 2026-10-02: open decisions decided

Amish, 2026-10-02: "i approve your recommendations for all 555 open decisions." The recommendations written for this repo's open decisions are recorded as decided.

### Decisions recorded

13 decisions, moved from "Open decisions" to "Decisions made" in the register (DKH-DEC-001 v0.3): design for construction P1 to P12 accepted (DKH-DDR-003); stainless piano hinges with peened pins for the prototype (A2); R6 restated as about 9 % with normal routing; R9 restated as full-rate charging up to about 30 °C ambient with daytime pauses accepted and the cold-soak limit stated; a station-owned pack pool exchanged one for one; a delivery-worker group in New York City with Los Deliveristas Unidos (Workers Justice Project) as the first candidate partner; UL 9540A unit-level propagation as the later aim, self-run first; aerosol unit kept, vermiculite floors as a trial variant; first pilot on private property with an existing circuit; anonymous prepaid NFC cards with a pack deposit; solid steel doors in the build, windows in renders only; render scene, sign and markings accepted with a "four-bay fit shown" caption; re-render to the constructable design.

### Documents changed

- `docs/06-design-decisions.md`: DKH-DEC-001 v0.3
- `docs/decisions/0001-trl2-review-decisions.md`: DKH-DDR-001 v0.3
- `docs/decisions/0002-recommendations-accepted.md`: DKH-DDR-002 v0.2
- `docs/decisions/0003-design-for-construction.md`: DKH-DDR-003 v0.3 (accepted; status kept Draft)
- `docs/01-problem.md`: DKH-PRB-001 v0.5 (site, partner, pack ownership)
- `docs/02-concept.md`: DKH-PRC-001 v0.7 (R6, R9 and open questions)
- `docs/03-requirements.md`: DKH-REQ-001 v0.7 (R6 and R9 restated; status)
- `docs/04-calcs/01-sizing.md`: DKH-CAL-001 v0.5 (requirement table and summary; no figure changed)
- `docs/05-build-plan.md`: DKH-BLD-001 v0.3 (safety stop S7: private site)
- `README.md` (not controlled): R6 and R9 wording

### Follow-up actions to carry approved decisions into the design

1. Decision 3: try switching the MPPT output to the bay with the flattest pack as a TRL 4 controller change, and re-run the solar share in `docs/04-calcs/sizing.py` if it is adopted (calculations).
2. Decision 4: state the restated R9 limits (about 30 °C full-rate charging, about -1 °C cold-soak start) in the R9 section of DKH-CAL-001 when `sizing.py` is next re-run (calculations).
3. Decision 7: plan the self-run heater-triggered propagation trial at an outdoor test site as TRL 4 or later work (docs).
4. Decision 8: add a vermiculite-filled bay floor variant to the model and BOM as a trial option when the propagation trial is planned (model, BOM).
5. Decision 9: choose the anchors and pad for the private host's ground; add them to the BOM (R15, register To confirm item 9) (BOM).
6. Decision 10: add anonymous prepaid NFC cards with a pack deposit to the access panel's token list design; no cabinet change (docs).
7. Decision 12: caption the product renders "four-bay fit shown" and settle the header sign wording with branding (pictures).
8. Decision 13: re-render `media/render-*.png`, `media/card.png` and `media/social-preview.png` on Amish's Mac to the constructable design (piano hinges, 150 mm door openings, vent hood), with door windows in the renders only (decision 11) (pictures).
9. Decision 6: approach Los Deliveristas Unidos (Workers Justice Project) as the first candidate partner; nothing is agreed (docs).

### Points found in the review

- R9 also fails at the cold end (cold-soaked packs cannot start charging below about -1 degrees), but item 4 only asks about the hot end. The restated R9 now states the cold-soak limit.
- The $1,214 cost excludes the anchors and pad that R15 needs (four anchors of 3.8 kN design tension), so the value-engineering comparison leaves out a safety-critical part.
- The two-bay first prototype serves 9 of 20 riders a day, so any pilot needs the four-bay fit ($1,438), which is $238 over the target as defined.

## Session 2026-10-01: constructable design and prototype build plan (kit 1.7.0)

Kit 1.7.0 installed (`.kit/`, `.claude/commands/`, `CLAUDE.md`). Following `/build-plan` and STANDARDS section 18, under Amish's 2026-09-30 instruction ("If you are realising that the design cannot be built as per concept - fix the design assumptions to match and be physically feasible as you draw the illustrations."), the model was made constructable and the illustrated build plan written. No hardware was built or bought; `trl` stays 3.

### Design changes made for construction (DKH-DDR-003, Draft, open for Amish's review)

1. Cabinet body: one closed box became six riveted 1.5 mm panels (laser-cut front, back, two sides, floor pan, roof) with folded flanges and corner reliefs.
2. Roof frame: two 40 x 40 x 4 mm angle beams under the post lines with bolted cleats and welded nuts; the canopy posts bolt through the roof into them (the posts stood on the bare roof sheet).
3. Canopy: posts on welded base and cap plates cut to 10°; rails lengthened 1,054 to 1,174 mm; four end clamps hold the panel (posts, rails and panel did not touch).
4. Plenum wall: 10 mm slab became 1.5 mm folded sheet with a vent port behind each bay (the liner ports opened onto a solid wall); notched for the beams.
5. Vent: two 110 mm roof holes, square fans on spacers and a folded vent hood with twelve rear slots replace the solid louver block (fans did not fit under it and the roof had no hole). Outlet 158 to 240 cm².
6. Bay doors: openings 172 to 150 mm; 172 x 526 x 2 mm doors on stainless piano hinges, EPDM gasket, lock tongue into a solenoid lock on the liner wall.
7. Cradle: receptacle and cradle overlapped inside one part; now one printed cradle (flame-retardant V-0) with its guides, receptacle in a pocket underneath, folded steel catch bracket screwed to the liner.
8. Liners, deck and charger shelf: fixed with flanges and blind rivets (they floated); the 10 mm rack plate became a folded shelf.
9. Electrical boxes, aerosol unit and detector: screwed to the back panel or roof (they floated); grid box 210 to 200 mm tall.
10. Plinth: solid ring became a welded 100 x 50 x 5 mm channel frame; eight M10 floor bolts; anchors moved to 25 mm from the ends so a socket reaches them through capped floor holes.
11. Service door: opening 960 to 900 mm wide for a hinge land; door on a piano hinge with gasket, cam lock and filtered intake slot.
12. Assembly order: roof built as a sub-assembly and lowered in last, cleat bolts from outside.

`python cad/src/model.py --check`: 41 components, no overlaps, all 60 joints touching (two-bay fit); four-bay fit also clean.

### Files

- `cad/src/model.py` rewritten (components one by one, fit check, clearances); STEP and STL regenerated in `cad/step/` and `cad/stl/`.
- `cad/src/build_plan_media.py` (new): `docs/05-build-plan/overview.png`, 18 making sketches `cad/drawings/DKH-DWG-101` to `118`, 10 joint pictures, 22 step pictures.
- `docs/05-build-plan.md` (DKH-BLD-001 v0.1), `docs/06-design-decisions.md` (DKH-DEC-001 v0.1), `docs/decisions/0003-design-for-construction.md` (DKH-DDR-003 v0.1, Draft).
- DKH-DWG-001 Rev P2; concept media regenerated (`media/hero.png`, blueprint, exploded, cutaway, flow, `model.glb`, `viewer.html`).
- DKH-CAL-001 v0.3 (`sizing.py` rerun), DKH-PRC-001 v0.5, DKH-REQ-001 v0.5, `bom/bom.csv` (lines 1, 2, 3, 10, 12, 14, 15, 16), `project.yaml` (`design_state: constructable`, evidence), `README.md` (links, "Building the prototype"). PDFs in `docs/pdf/`.

### Key results

- Mass 217 kg (two-bay prototype, no packs; was 205 kg); 247 kg with four bays and three packs. Front anchor design tension 3.79 kN. Lowest canopy point over the walkway 2.17 m.
- **R16 now not met:** $1,214 against $1,200 (end clamps and post plates +$10, service door hinge +$5). R6 and R9 still not met; R8 and R15 at risk; R7 and R14 not verifiable; nine met.

### Proposed, awaiting Amish (all in the design decisions register)

- Accept DKH-DDR-003 (changes P1 to P12).
- R16: raise `budget_usd` to $1,250 (recommended), recover $14 at supplier selection, or accept not met. `budget_usd` is unchanged.
- Door hinges outside the front panel (R10): piano hinges with peened pins for the prototype (recommended), or concealed hinges.
- The earlier open items (pack ownership, pilot site, R6, R9 and the render choices) are carried into the register.

### Safety

Unchanged hazards: lithium-ion packs beside a walkway, mains in the technical compartment (electrician only), canopy uplift (anchors mandatory). New in the build plan: zinc fumes when welding galvanized steel, sharp sheet edges, a 217 kg cabinet to be moved with equipment, and work at height for the canopy. The plan's safety stops S1 to S7 cover them.

### Recommended next step

Amish to review DKH-DDR-003 and decide the R16 budget question; then re-render the product images on the Mac.

## Session 2026-09-25: recommendations accepted

Amish wrote on 2026-09-25: "i accept all your recommendations, go with them across all repos." Recorded in `docs/decisions/0002-recommendations-accepted.md` (DKH-DDR-002 v0.1).

### Decisions applied and what changed

Twelve items are now **Decided by Amish, 2026-09-25: go with recommendation**: DKH-DDR-001 items 1 to 9, 12 and 13, and the two-bay first prototype (with item 1). All were already built into the TRL 3 model, BOM, drawing and calculations, so no number or geometry changes:

| Item | Before | After |
| --- | --- | --- |
| Budget (R16) | $1,200, four-bay cabinet with two bays fitted, adopted pending review | $1,200, same scope, decided; parts $1,199 (unchanged) |
| Solar target (R6) | 10 % (relaxed from 20 %), adopted pending review | 10 %, decided; calculated 9.3 % (unchanged) |
| Release threshold, charger power factor, flush plinth, demand profile | Engineering proposals | Decided: 80 % state of charge, power factor 0.9 or better, 1,000 x 500 mm plinth, 15 min patience |
| Items 3 to 9 (one row of four bays, charger and CAN per bay, steel compartments and plenum, doors locked in alarm, MPPT to bay 1, offline NFC, 70 % health gate) and SwapCell interface v0.3 | Adopted pending review | Decided |

Files changed: DKH-DDR-001 v0.2, DKH-PRC-001 v0.4, DKH-REQ-001 v0.4, DKH-CAL-001 v0.2 (wording only; `sizing.py` rerun, results unchanged), `bom/bom-notes.md`, `project.yaml` (evidence list), `README.md` (decision link and a new "What sparked the idea" based on the NYC DOT 2024 battery charging pilot). `budget_usd`, pitch and problem are unchanged. DKH-DWG-001 was regenerated at Rev P1 (no geometry or note change). All PDFs, drawings and media were regenerated for the designmolecule.com footer.

### Requirement status (unchanged by the decisions)

| Status | Requirements |
| --- | --- |
| Not met | R6 (9.3 % solar against 10 %), R9 (charging pauses above about 29 to 39 °C ambient) |
| At risk | R8 (containment needs a propagation test), R15 (anchors and pad not chosen), R16 ($1,199 against $1,200) |
| Not verifiable at TRL 3 | R7, R14 |
| Met | R1, R2, R3, R4, R5, R10, R11, R12, R13 |

### Still awaiting Amish (no recommendation was made)

- Pack ownership model (station pool, rider exchange or fleet packs).
- First pilot site and partner.
- How to close R6: accept about 9 %, route flat packs to bay 1 in daylight, feed more bays from the sun, or drop the target.
- How to close R9: accept daytime pauses, add active cooling, narrow the design ambient, or raise the charge temperature limit with SwapCell.

### Cross-repo actions

- SwapCell: ask for the pack wake time on the coded INTERLOCK loop, which sets DockHub's 2 s return check.
- SwapCell: note that multi-bay hosts need a CAN channel per bay because packs default to node 0.

No other repo was edited.

### TRL 4

TRL 4 remains on hold by Amish's instruction. No build, test, PCB, firmware or purchasing was started; `trl` and `trl_target` stay at 3.

## Session 2026-09-25: TRL 3

### What was done

- `docs/decisions/0001-trl2-review-decisions.md` (DKH-DDR-001 v0.1): the nine TRL 2 points that carried a recommendation are adopted as recommended for TRL 3 under Amish's 2026-09-25 instruction, open for his review; four items remain open.
- `docs/04-calcs/01-sizing.md` (DKH-CAL-001 v0.1) with `docs/04-calcs/sizing.py` and `docs/04-calcs/results.csv`: charging, swap time, a minute-step day model for throughput and solar share, daily energy, grid current with power factor, cabinet and pack thermal, fire detection latency and vent path, reach and footprint geometry, CAN load, mass, wind and anchoring, and cost, with a results table for R1 to R16.
- `cad/src/model.py`: parametric build123d model (cabinet, bays with SwapCell v0.3 cradle, guides, class D catch and coded receptacle, reference packs with plug, handle and latch pawl, chargers, controller, access panel, grid unit, fire unit, plenum with fans and louver, canopy, flush plinth with anchor holes, service door). `bays_fitted` switches between the two-bay prototype and the four-bay fit. Exports `cad/step/` and `cad/stl/` (`dockhub-assembly`, `dockhub-assembly-4-bays`, `dockhub-cabinet`, `dockhub-bay`, `dockhub-canopy`); clash check finds none in either fit.
- `cad/src/sheets.py` and `cad/drawings/DKH-DWG-001.svg`, `.pdf`, `.png`: general arrangement of the first prototype (bays 1 and 2 fitted) at Rev P1, marked not for fabrication. DKH-DWG-001 was free because the concept blueprint uses DKH-DWG-010.
- `bom/bom.csv` (16 lines, every line priced with a supplier type) and `bom/bom-notes.md`, now for the two-bay fit.
- `cad/src/concept_media.py` now builds from `model.py` (four-bay fit, three packs, one empty bay); hero, blueprint, cutaway, exploded, flow, `model.glb` and `viewer.html` regenerated and checked by eye; temporary `media/_views*` folders deleted. The kit's cutaway works as is because the model is centered on the origin.
- `docs/01-problem.md`, `docs/02-concept.md` and `docs/03-requirements.md` moved to v0.3 with the adopted items, SwapCell interface v0.3 and numbers from DKH-CAL-001. `project.yaml`: trl 3, trl_target 3, trl_evidence updated; `budget_usd` unchanged at 1200. `README.md`: TRL badge, links, concept numbers, components, BOM and safety text.

### Requirements (DKH-CAL-001)

| ID | Result | Status |
| --- | --- | --- |
| R6 | 9.3 % of charging energy from the canopy (0.74 of 1.38 kWh used); 11.4 % if flat packs are routed to bay 1 in daylight, which turns one rider in 20 away | **Not met** (target relaxed to 10 %) |
| R9 | The pack refuses charge above 45 °C; charging pauses above about 29 to 39 °C ambient and for cold-soaked packs below about -1 °C | **Not met** |
| R8 | Containment needs a propagation test | At risk (not verifiable at TRL 3) |
| R15 | 2.91 kN·m overturning against 0.50 kN·m self-weight; four anchors of 3.8 kN design tension each and a pad, neither chosen | At risk |
| R16 | $1,199 against $1,200 with two of four bays fitted | At risk |
| R7, R14 | Detection latency 3.1 s and contactor 0.15 s on paper; 15 min part swap needs a trial | Not verifiable at TRL 3 |
| R1, R3, R4, R5, R11, R13 | 31 s swap; 1.2 h and 2.3 h charge; 20 of 20 served with four bays; 1.25 kW, 11.0 A at 120 V with power factor 0.95; reach 0.73 to 1.10 m; 1.0 x 0.5 m, canopy 2.18 m clear | Met |
| R2, R10, R12 | SwapCell v0.3 interface, security features, data | Met (design review) |

Counts: 2 not met, 3 at risk, 2 not verifiable at TRL 3, 9 met.

Findings that change the TRL 2 picture:

- A swap needs an empty bay, so *n* bays hold *n* - 1 packs. Four bays give 36 swaps a day at most (TRL 2 said 38). The adopted two-bay prototype holds one pack and serves only 9 of the 20 duty-case swaps: it can demonstrate the station but not run the duty case.
- R5 holds only with power-factor-corrected chargers; at a power factor of 0.6 four chargers draw 17.2 A at 120 V. Line 5 of the BOM now specifies 0.9 or better.
- The cabinet air rises only about 4 to 5 K, not 10 K, but R9 is set by the pack's own 45 °C charge limit, so shading cannot fix it.
- Mass is about 205 kg (prototype, no packs) to 234 kg (four bays, three packs), not 150 to 170 kg.
- Wind: the canopy force is mostly uplift (1,590 N); overturning is 2.91 kN·m, not 3.6 kN·m, but the cabinet still tips and slides without anchors. Front canopy posts pull about 1.25 kN each on the roof frame.
- The TRL 2 plinth (1,020 x 520 mm) broke the 1.0 m width limit of R13; it is now flush with the body.
- SwapCell pack price is $414 (SWC-CAL-001), not $370.

### Decisions recorded (DKH-DDR-001)

Decided by Amish, 2026-09-25: go with recommendation (first adopted for TRL 3 pending his review; see DKH-DDR-002): build the four-bay cabinet and fit two bays for the first prototype, with `budget_usd` unchanged at $1,200 and redefined to that fit (option (b), $1,450, was not recommended and is not adopted); keep the 400 W canopy and relax R6 to 10 %; four bays in one row; one charger and CAN channel per bay; per-bay steel compartments with a rear plenum; doors locked during a fire alarm; MPPT to bay 1; offline-first NFC access; a 70 % state-of-health gate. The pitch and problem lines had no recommended rewording, so `project.yaml` and the README pitch are unchanged.

### Still awaiting Amish

- Pack ownership model (no recommendation at TRL 2; to follow co-design).
- First pilot site and partner (no recommendation at TRL 2).
- R6 is still not met at 10 %: accept about 9 %, route packs to bay 1 in daylight and accept occasional waits, feed more bays from the sun, or drop the target. No recommendation made.
- R9 is not met: accept daytime charging pauses in hot climates, add active cooling, narrow the design ambient, or raise the charge temperature limit with SwapCell. No recommendation made.
- Whether a two-bay first prototype that cannot run the duty case is acceptable. Decided by Amish, 2026-09-25, with item 1 (two bays fitted): go with recommendation.
- Engineering proposals from this session (DKH-DDR-001 items 12 and 13): SwapCell interface v0.3, an 80 % release level, chargers with a power factor of 0.9 or better, the flush plinth, and the demand profile and 15 min rider patience used in the day model. Decided by Amish, 2026-09-25: go with recommendation.

### Safety concerns

- Lithium-ion packs of 468 Wh beside a public walkway; fire containment between bays (R8) is unproven and needs a propagation test, which is TRL 4 work and on hold.
- The canopy lifts and tips the cabinet in a 30 m/s gust. Anchors of at least 3.8 kN design tension each into a concrete pad are mandatory, and the canopy posts must bolt through to a roof frame. The pad and anchors are not in the BOM.
- Chargers without power factor correction can overload a 120 V branch circuit.
- A pack can deliver about 500 A into a short; each bay's DC line needs a 60 V DC fuse with at least 1 kA breaking capacity (now in BOM line 16).
- Charging stops in hot weather by design (pack limit 45 °C); the controller must never override that.
- The cabinet weighs about 205 kg empty; it must be moved with lifting equipment.

### Problems and notes

- Shared components: DockHub depends on none of FieldNode, CellGuard, MotionCore, ThermaCart, TwinKit or CalRig; TwinKit stays a later suggestion. SwapCell (reference repo, read-only) is at interface v0.3; DockHub now builds to it, and no conflict was found. The observation that multi-pack hosts need a CAN channel per bay or unique node numbers stands; v0.3 allows node numbers 0 to 7 but packs default to 0.
- The 2 s return check in the swap time depends on how fast a sleeping pack wakes on the coded INTERLOCK loop; SwapCell v0.3 gives no wake time. Worth raising with SwapCell.
- No TRL 4 material exists (`build-log/` holds only its README; `electronics/` and `firmware/` are empty). None was created.
- No unchecked citations were listed at TRL 2, so no WebFetch checks were needed. The README's cited figures are unchanged.
- Process note: during this session one read-only `git status` call was run by mistake (its output was discarded), against the instruction not to run git commands. Nothing was staged, committed or changed by it.

### Recommended next step

TRL 4 is on hold by Amish's instruction, so the next step is a decision, not a build: Amish to review the adopted items in DKH-DDR-001, choose how to handle R6 and R9, decide whether the two-bay first prototype is acceptable, and choose the pack ownership model and first pilot site. For the record only, TRL 4 would need a bench test article of one bay (cradle, coded receptacle, charger, contactor and detection chain), named charger, anchor and aerosol parts with datasheets, a lab test report (TST, environment: lab) covering detection latency and charge pausing, and build log entries; a propagation test for R8 would follow later at an accredited lab.

## Session 2026-09-25: /populate to a strong TRL 2

### What was done

- `docs/01-problem.md` (DKH-PRB-001 v0.2): problem with cited fire and charging-time figures, users, operating environment, constraints, out of scope, prior work (Ampersand, Swobbee, Gogoro, India's draft swapping policy, SwapCell), open questions; co-design checklist kept.
- `docs/03-requirements.md` (DKH-REQ-001 v0.2): 16 measurable requirements (R1 to R16) with targets, verification and TRL 2 status, a design duty case and assumptions.
- `docs/02-concept.md` (DKH-PRC-001 v0.2): how it works, 15 numbered components, first-order numbers, eight design choices, relationship to SwapCell, safety section, open questions.
- `cad/src/concept_media.py`: massing model of the cabinet, bays, packs, chargers, controller, access panel, grid input, fire parts, plenum and louver, solar canopy, plinth and service door, in street context (sidewalk, curb, roadway) with the 1.75 m figure.
- `media/`: `hero.png`, `concept-blueprint.png`, `.pdf` and `.svg`, `model.glb` and `viewer.html`, `exploded.png` (callouts 1 to 15 match the BOM), `cutaway.png`, `flow.png` (daily energy, all values estimates). Temporary `_views` folders removed.
- `bom/bom.csv`: 16 lines with indicative USD prices, numbered to match the exploded view; `bom/bom-notes.md` updated.
- `README.md`: hero image and links line; Concept rationale, Burning platform, Where it could be used (6 industries, 6 regions), What sparked the idea, Problem, Concept, Key components and Safety expanded with cited sources.
- `docs/pdf/`: branded PDFs of the three controlled documents.

### Key results (estimates, to be checked at TRL 3)

| Quantity | Estimate | Requirement |
| --- | --- | --- |
| Swap time | about 30 s | R1 met |
| Charge per bay | about 1.2 h (20 to 80 %), 2.3 h full | R3 met |
| Maximum throughput, 4 bays | about 38 swaps a day | R4 met |
| Peak grid draw | about 1.25 kW (10.4 A at 120 V) | R5 met |
| Daily energy at 20 swaps | about 10.1 kWh in, 8.0 kWh stored in packs | |
| Solar share (400 W canopy) | about 1.3 kWh a day, 13 % | **R6 not met** (target 20 %) |
| Interior air at 45 °C ambient | about 55 °C | **R9 not met**: charging derates or pauses |
| Fire containment between bays | not calculated; needs a test | **R8 unverified, at risk** |
| Canopy wind overturning, 30 m/s gust | about 3.6 kN·m against about 0.4 kN·m self-weight | R15 met only if anchored |
| Mass with four packs | about 150 to 170 kg | |
| Parts cost, packs excluded | about $1,423 (4 bays fitted); about $1,199 (2 of 4 fitted) | **R16 not met with 4 bays** |

Requirements not met or at risk: R6 (solar share), R9 (charging at 45 °C ambient), R8 (fire containment unproven), R16 (cost with four bays). R15 depends on anchoring to a concrete pad that is not in the BOM.

### Proposed, awaiting Amish

1. **Budget (R16).** Options: (a) build the four-bay cabinet but fit two bays for the first prototype, about $1,199; (b) raise `budget_usd` to $1,450; (c) a two-bay cabinet. Recommendation: (a). `project.yaml` is unchanged. **Decided by Amish, 2026-09-25: go with recommendation.**
2. **Solar target (R6).** Options: keep the 400 W canopy as shade and supplement and relax R6 to 10 %; drop the canopy; or add an off-cabinet array. Recommendation: relax R6 to 10 %. **Decided by Amish, 2026-09-25: go with recommendation.**
3. **Pack ownership model:** station-owned pool, rider-owned one-for-one exchange, or fleet packs. The pack pool (about $370 per pack) costs far more than the station. No recommendation until co-design. Still proposed, awaiting Amish (no recommendation).
4. Four bays in one row at hand height rather than eight in two rows. **Decided by Amish, 2026-09-25: go with recommendation.**
5. One certified charger and one CAN channel per bay rather than a shared charger matrix. **Decided by Amish, 2026-09-25: go with recommendation.**
6. Separate steel compartment per bay with a rear plenum venting through the roof. **Decided by Amish, 2026-09-25: go with recommendation.**
7. Bay doors stay locked during a fire alarm. **Decided by Amish, 2026-09-25: go with recommendation.**
8. Solar through an MPPT controller to bay 1 rather than a hybrid inverter. **Decided by Amish, 2026-09-25: go with recommendation.**
9. Offline-first NFC access with an optional app. **Decided by Amish, 2026-09-25: go with recommendation.**
10. State-of-health gate at 70 % for releasing packs to riders. **Decided by Amish, 2026-09-25: go with recommendation.**
11. First pilot site and partner (a delivery-worker group in a high-income city, or a moto-taxi hub in East Africa). Still proposed, awaiting Amish (no recommendation).
12. `project.yaml` pitch and problem were checked against the sources and left unchanged.

### Safety concerns

- Up to four 468 Wh lithium-ion packs beside a public walkway. Fire containment between bays (R8) is unproven and can only be shown by a propagation test at TRL 4 or later; the aerosol unit does not stop a cell in runaway.
- Mains AC in the technical compartment: electrician installation, RCD, per-charger breakers, surge protection, lockable isolator, earth bonding, separation from the 54.6 V DC side.
- Heat: a sunlit cabinet can exceed pack charge limits; the controller must pause charging.
- Wind: the canopy creates an overturning moment several times the cabinet's self-weight resistance; anchoring is mandatory.
- Siting: keep the vent louver away from doors, windows and people; keep a clear pedestrian path.

### Problems and notes

- SwapCell interface observation, raised for that project rather than changed here: several packs on one host collide at node 0 unless each bay has its own CAN channel (as proposed) or packs get unique node numbers.
- TwinKit is mentioned only as a later suggestion for collecting logs.
- The legacy `cad/src/model.py` placeholder is untouched (TRL 3 work).
- WebSearch was unavailable this session. Every cited figure was verified by fetching the source page directly. Gogoro network figures and New York's delivery-worker numbers could not be verified and are left out.

### Recommended next step

Review this note and the media, then decide items 1 to 3. If approved, run `/advance-trl3` to check the thermal, wind, energy and throughput estimates by calculation, and produce the parametric model and drawing sheet.

## Session 2026-09-26: product appearance model and photoreal renders

Amish chose this repo for the first batch of product renders on 2026-09-26.

### What was added

`cad/src/product_model.py` exposes `product_parts()` (118 parts: 64 shell, 34 internal, 8 accessory, 12 context), `TITLE` and `RENDER_VIEWS` (hero, exploded and a detail view of the cabinet without canopy or street). It imports PARAMS, `bay_x()`, `pack_z0()` and the box helper from `cad/src/model.py`; the cabinet, plinth, bay openings, doors and handles, bay compartments, SwapCell v0.3 pack envelope (plug, handle, latch pawl), access panel, chargers, controller, grid unit, MPPT controller, fire unit, plenum, fans, louver, canopy and service door keep the model.py sizes and positions. It adds:

- Cabinet: rounded vertical corners and top edges, fold seams on the sides, rivet rows, filtered intake slots with filter pads, EPDM gasket outlines round every door, and a dark header sign with raised "DockHub" lettering and a teal accent band.
- Bay doors: teal steel doors with a clear polycarbonate window and gasket, metal pull handle, hinges, lock indicator, raised bay number and a status light (bay 2 and 3 green, bay 4 amber, lit). Bay 1 is shown open and empty.
- Bay compartments split into liners, cradles, receptacles with contact pins, side guides and class D catches; SwapCell packs with filleted cases, a parting line, rubber handle, teal stripe, label, wake button and a lit charge gauge.
- Access panel: steel bezel with security screws, display with lit screen content (title bar, "Tap to swap" and four bay tiles), NFC reader with a lit ring and contactless symbol, four bay status lights and a buzzer grille.
- Service door with intake louvers and filter, cam lock, hinges, a lithium battery warning label and an operator information plate; plinth with a shadow line under the body.
- Roof louver with rain hood and insect mesh; canopy with an aluminium-framed solar panel showing its cell grid, junction box, rails, posts, base plates and bolts (group "accessory").
- Technical compartment for the exploded view: chargers with heat sink fins and labels on their rack, controller enclosure with status lights and LTE-M antenna, grid unit with breakers and a red isolator, MPPT controller with fins and display, aerosol unit with straps, detector, plenum wall with vent ports, fans and guards.
- Context (not in the BOM): a paved sidewalk patch with a granite curb and the shared clay mannequin (1.75 m, "stand" with the right arm overridden) at bay 1, holding a charged pack by its handle bar.

`README.md` now shows `media/render-hero.png` and links `media/render-exploded.png`; the orchestrator produces both files.

### Differences from model.py (Proposed, awaiting Amish)

1. **Clear windows in the bay doors.** BOM line 2 specifies plain steel doors. The appearance model puts a polycarbonate window (about 102 x 245 mm) in each door so a rider can see a pack is present and the status light, and the renders show the internals. Proposed, awaiting Amish. Recommendation: keep solid steel doors for the build, because a window weakens the door as a fire and vandal barrier (R8, R10), and treat the windows as render-only; option: fire-rated glazing, which would need pricing against R16.
2. **Which bay is empty.** model.py leaves the last fitted bay (bay 4) empty; the hero shows the moment after a swap, with bay 1 open and its pack in the rider's hand and packs in bays 2 to 4. Proposed, awaiting Amish. Recommendation: accept as a render scene state; no geometry changes.
3. **Header sign, labels and markings.** The header sign, bay numbers, warning label and information plate are appearance detail on the cabinet (BOM lines 1 and 16); no new BOM lines are implied. Proposed, awaiting Amish. Recommendation: accept, and settle sign wording with the branding decision.
4. **Louver rain hood and base plates.** BOM line 10 names a rain hood and line 12 says the posts bolt to the roof frame; model.py shows neither. The appearance model adds a 6 mm hood over the louver and 8 mm post base plates. Proposed, awaiting Amish. Recommendation: accept; the canopy heights and the 2.45 m front edge are unchanged.
5. **Four-bay fit.** As in the concept media, the renders show all four bays fitted, not the two-bay first prototype. Proposed, awaiting Amish. Recommendation: say "four-bay fit shown" in the caption.

### Status

This is an appearance model only: no tolerances, no fabrication detail, nothing past TRL 3. `trl: 3` and `trl_target: 3` are unchanged, and TRL 4 remains on hold. model.py, the BOM and the other documents were not edited.

## Session 2026-09-27: kit 1.5.0 and image quality

- Kit 1.5.0 synced: STANDARDS v1.5 (sections 12 to 15: product renders, storefront images and image quality, public release, authorship and signing), `.kit/cards.py`, `.kit/image_qc.py`, `.kit/release_gate.py`, issue templates, and the `/render-product` and `/release` commands. `CLAUDE.md` now matches `.kit/CLAUDE.md`.
- Every `media/render-*.png` recaptioned from its original render with the new layout: the title, concept label and repository sit in a band above the render and the view note in a band below it, each line wrapped to the image width, so no text overlaps other text or the render or runs off the image. `media/card.png` and `media/social-preview.png` regenerated with the same rules.
- `python .kit/image_qc.py` and `python .kit/release_gate.py` pass. trl stays 3.

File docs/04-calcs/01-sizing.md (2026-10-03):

---
doc_id: DKH-CAL-001
title: DockHub sizing calculations
project: DockHub
doc_type: Calculation note
version: "0.6"
status: Draft
date: '2026-10-02'
author: Amish Chadha
license: CERN-OHL-S-2.0
revisions:
- version: "0.1"
  date: '2026-09-25'
  author: Amish Chadha
  change: First TRL 3 sizing note (charging, swap time, throughput and solar day model, grid, thermal, fire timing, geometry, mass, wind and anchoring, cost) against SwapCell interface v0.3
- version: "0.2"
  date: '2026-09-25'
  author: Amish Chadha
  change: Recommendations accepted by Amish (DDR-002)
- version: "0.3"
  date: '2026-10-01'
  author: Amish Chadha
  change: Constructable design (DKH-DDR-003). Mass, wind, vent path, canopy height and cost rerun; R16 now not met ($1,214)
- version: "0.4"
  date: '2026-10-01'
  author: Amish Chadha
  change: Budget treated as a value-engineering target
- version: "0.5"
  date: '2026-10-02'
  author: Amish Chadha
  change: "Requirement table and summary: R6 and R9 against the targets restated on 2026-10-02 (DKH-DEC-001); no figure changed"
- version: "0.6"
  date: '2026-10-02'
  author: Amish Chadha
  change: "Approved follow-ups: sizing.py rerun against the restated R6 and R9; flattest-pack solar switching as a sensitivity; R9 limits stated; anonymous prepaid cards in the token list; anchors and site pad chosen and checked (R15 met); cost with anchors and pad (USD 1,519)"
---

# DockHub sizing calculations

On paper, the four-bay DockHub meets eleven of its sixteen requirements. **One is over its value-engineering target:** R16, where the anchors and site pad chosen on 2026-10-02 (USD 305) join the parts added to make the design buildable, bringing the estimated cost of the two-bay prototype to USD 1,519 against the USD 1,200 target. Two are **at risk**: R8 (fire containment, which only a propagation test can show) and R9 (against the target restated on 2026-10-02, full-rate charging up to about 30 °C ambient, the warmest bay may pause just under 30 °C). R7 and R14 cannot be verified until hardware exists. Against the targets Amish restated on 2026-10-02 (DKH-DEC-001), R6 is met with a thin margin (9.3 % against about 9 %), and R15 is now met: four M12 wedge anchors and a 1,400 x 1,100 x 300 mm cast pad hold the cabinet at a 30 m/s gust, subject to confirming the anchor rating from the maker's data.

Two findings change the TRL 2 picture. First, a swap needs an empty bay for the returned pack, so a station with *n* bays holds *n* - 1 packs. The four-bay station has three working packs (36 swaps a day at most, released full), and the two-bay first prototype has one, which serves only 9 of the 20 duty-case swaps. Second, the cabinet with its canopy frame weighs about 217 to 247 kg, not 150 to 170 kg.

Every number here is printed by `docs/04-calcs/sizing.py` (run from the repo root: `python docs/04-calcs/sizing.py`), which also writes `docs/04-calcs/results.csv`. The script reads the geometry parameters from `cad/src/model.py` and the costs from `bom/bom.csv`. All values are first-principles estimates; nothing is measured.

## 1. Assumptions

*Table 1. Inputs. All are assumptions for a paper design.*

| Input | Value | Basis |
| --- | --- | --- |
| Pack | 13S2P, 46.8 V nominal, up to 54.6 V, 10 Ah, 468 Wh, 110 mΩ, 2.85 kg, 393 mm overall; charge window 0 to 45 °C | SwapCell interface v0.3, SWC-CAL-001 |
| Pack heat path | 1.17 W/K to the surrounding air, 32 min time constant | SWC-CAL-001 (open air) |
| Charger | 5 A CC to 85 %, then CV tapering linearly to 1 A (0.6 h); 90 % efficient; 303 W input at the end of CC | SWC-CAL-001; certified charger |
| Cell charge efficiency | 95 % for energy accounting; heat in the pack between I²R (2.75 W) and all of the 5 % loss (13.7 W) | SWC-CAL-001 |
| Duty case | 20 swaps a day, packs returned at 15 %, released at 80 % or more (fullest first) | DKH-REQ-001; release threshold decided by Amish, 2026-09-25 (DKH-DDR-002) |
| Demand profile | Arrivals at 07:30, 08:30, 09:30, 11:00, 11:45, 12:15, 12:45, 13:15, 14:00, 15:30, 16:30, 17:30, 18:00, 18:30, 19:00, 19:30, 20:00, 20:30, 21:15 and 22:30; a rider leaves after waiting 15 min | Lunch and dinner peaks; to be tested with riders |
| Cabinet loads | 30 W average, 40 W peak | Controller, modem, display, lights, fans, locks |
| Charger power factor | 0.95 with power factor correction, 0.6 without | Typical ranges; the chosen charger must be checked |
| Branch circuit | 120 V 15 A or 230 V 10 A, continuous load 80 % of the rating | Common practice for continuous loads |
| Solar | 400 W, 4.5 peak sun hours on a sine profile from 06:00 to 18:00, 0.8 derate, MPPT 96 %, 50 V mean charging voltage; bay 1 uses the MPPT when it offers 50 W or more, otherwise its AC charger | Clear day in a sunny city; control rule for the MPPT to bay 1 decided by Amish, 2026-09-25 (DKH-DDR-002) |
| Cabinet heat transfer | Film coefficients 17 W/(m² K) outside and 8 W/(m² K) inside; two 120 mm fans at 90 m³/h free air each, half lost to the filter and the vent hood | Still air with light wind; typical fans |
| Sun on the cabinet | 500 W/m² on the front and one end wall, absorptance 0.35 (light powder coat); roof shaded by the canopy | Afternoon sun |
| Wind | 30 m/s gust, air 1.225 kg/m³; panel force coefficient 1.5 normal to the panel with the centre of pressure a quarter of the panel depth from its centre; body drag coefficient 1.3; posts 2.0; load factor 1.5 for the anchors; friction 0.4 | TRL 2 assumption for the panel; typical values otherwise |
| Steel | 7,850 kg/m³, 1.5 mm sheet, 15 % added for hems and flanges | Decided sheet gauge (R10) |

## 2. Charging (R3)

With the SwapCell charge profile, a pack charges from 20 to 80 % in **1.20 h** and from empty to full in **2.30 h** (1.70 h CC and 0.60 h CV). R3 (1.5 h and 2.5 h) is met. A pack returned at 15 % reaches the 80 % release level in 1.30 h and full in 2.00 h.

Each full recharge from 15 % stores 397.8 Wh, takes 418.7 Wh from the charger and 465.3 Wh from the grid, about $0.093 of electricity at an assumed $0.20/kWh. Each charger draws 303 W at the end of CC and loses about 30 W as heat.

## 3. Swap time (R1)

*Table 2. Task analysis for a rider who knows the station.*

| Step | Time (s) |
| --- | --- |
| Tap card or phone; token checked offline | 3 |
| Empty bay door unlocks | 1 |
| Open door, place the flat pack connector down | 8 |
| Close door | 2 |
| Controller confirms the return (door switch, coded INTERLOCK, pack identity on CAN) | 2 |
| Second door unlocks; open it and lift out the charged pack | 10 |
| Close door, step away | 5 |
| **Total** | **31** |

R1 (60 s) is met with a margin of about half. The 2 s return check depends on how fast a sleeping pack wakes on the coded INTERLOCK loop and answers the heartbeat; SwapCell interface v0.3 gives no wake time, so this is an assumption.

## 4. Throughput and solar share (R4, R6)

**One bay is always empty.** A swap starts by placing the flat pack in an empty bay, so a station with *n* bays runs with *n* - 1 packs. The ceiling is (*n* - 1) x 24 h divided by the recharge time: **36 swaps a day** for four bays with packs released full, or 55 at the 80 % release level; **12** (or 18) for the two-bay first prototype. At a peak, four bays can serve about 2.3 swaps an hour after the first three; two bays serve 0.77.

A minute-step model of the design day (the script runs three identical days and reports the third) gives Table 3.

*Table 3. Design day, 20 swaps, packs returned at 15 %.*

| Case | Served | Longest wait | Solar used | Solar share of charging energy |
| --- | --- | --- | --- | --- |
| Four bays, fullest pack released first | 20 of 20 | 4 min | 0.74 of 1.38 kWh | **9.3 %** |
| Four bays, bay 1 released first when the sun is up | 19 of 20 | 0 (one rider leaves after 15 min) | 0.86 of 1.38 kWh | 11.4 % |
| Two bays (first prototype) | 9 of 20 | 0 (11 riders leave) | 0.69 of 1.38 kWh | 19.9 % |

**R4 is met by the four-bay fit**: all 20 riders are served and only one waits, for 4 minutes. The two-bay prototype, adopted to meet the value-engineering target (DKH-DDR-001 item 1), can show the swap, charge and safety chain but cannot run the duty case.

**R6 is met with a thin margin.** The panel gives 1.44 kWh of DC on the design day and the MPPT delivers 1.38 kWh, but it can feed only bay 1. Bay 1 is sometimes the empty bay and at other times holds a pack that is already full, so only 0.74 kWh reaches a pack: 9.3 % of the charging energy against the target of about 9 % with normal routing restated on 2026-10-02 (it was 10 %). Sending flat packs to bay 1 in daylight raises the share to 11.4 %, but solar charging at up to 181 W is slower than the 5 A AC charger, so fewer packs are ready at the dinner peak and one rider in 20 leaves. The TRL 2 estimate of 13 % assumed all the solar energy would be used. The peak MPPT output of 181 W is below the 5 A bay limit (about 250 W), so there is no clipping on the design day.

**Sensitivity: solar switched to the flattest pack.** Amish decided on 2026-10-02 that switching the solar charger to whichever bay holds the flattest pack is to be tried as a TRL 4 controller change, not a cabinet change. As a sensitivity only, the script also runs that rule (the solar output follows the flattest pack still charging, and that bay's AC charger rests while it does): all 20 riders are served with no wait and the solar share rises to **16.1 %** (1.28 kWh of the 1.38 kWh available). The rule is not adopted; R6 is assessed with normal routing, and the share is rerun if the change is adopted after the TRL 4 trial.

## 5. Daily energy

At the duty case the four-bay station takes **8.76 kWh a day from the grid** (8.04 kWh to the chargers and 0.72 kWh for cabinet loads) and 0.77 kWh from the panel, and stores 7.58 kWh in the packs riders take away. Losses are 0.80 kWh in the chargers, 0.03 kWh in the MPPT and 0.40 kWh in the cells. Figure 2 of DKH-PRC-001 uses these values. Grid energy per swap, including the cabinet loads, costs about $0.088 at $0.20/kWh.

## 6. Grid supply (R5)

With four chargers at the end of CC and 40 W of auxiliaries, the peak real power is **1,253 W**, inside the 1.5 kW target (647 W with two bays fitted). In the day model at most three chargers run at once, because one bay is always empty.

*Table 4. Supply current with four chargers running.*

| Charger power factor | Apparent power | 120 V (12 A continuous limit) | 230 V (8 A continuous limit) |
| --- | --- | --- | --- |
| 0.95 (with correction) | 1,317 VA | 11.0 A | 5.7 A |
| 0.6 (without) | 2,062 VA | **17.2 A** | **9.0 A** |

R5 is met **only with chargers whose power factor is 0.9 or better**; without power factor correction four chargers overload a 120 V 15 A circuit and exceed the continuous limit of a 230 V 10 A circuit. `bom/bom.csv` line 5 now specifies this.

## 7. Thermal (R9)

The cabinet skin has an area of 5.20 m², a U-value of 5.44 W/(m² K) and a loss conductance of 28.3 W/K; the fans move 90 m³/h (53 cfm), worth 30.1 W/K. With three packs charging, the heat inside is 91 W from the chargers, 8 to 41 W from the packs, 30 W of cabinet loads and 118 W of sun through the walls. The cabinet air rises only **4.2 to 4.8 K** above ambient, less than the 10 K assumed at TRL 2, so at 45 °C ambient it is about 49 °C, not 55 °C.

That does not rescue R9, because the pack itself refuses to charge above 45 °C. By the end of the CC phase a pack is 2.2 to 10.8 K above the cabinet air, so **uninterrupted 5 A charging needs ambient air below about 29 to 39 °C**. At the 45 °C design ambient the packs are at 51 to 61 °C and do not charge at all; a fixed 5 A charger can only pause. At the cold end, an idle cabinet runs only 1.1 K above ambient with the fans off, so a pack that has cooled in the cabinet cannot start charging below about -1 °C; a pack returned warm from a ride can. The requirement that the station never charges outside the pack's window is met by the pack and the controller, but the original operating range of -10 to 45 °C for charging is not.

**R9 as restated on 2026-10-02 (DKH-DEC-001).** Amish kept the pack's 45 °C charge limit and accepted daytime pauses. The restated limits are: the station stores packs and serves swaps at -10 to 45 °C ambient; it charges at the full 5 A rate up to about **30 °C ambient**, and above that it may pause charging in the daytime; it does not start charging a cold-soaked pack below about **-1 °C ambient** (calculated -1.1 °C); and it never charges a pack outside the pack's reported window. Against these limits the calculated full-rate limit of about 29 to 39 °C leaves the warmest bay, with the upper bound on pack heat, able to pause just under 30 °C, so **R9 is at risk** rather than met. The first pilot site is chosen with summer highs near 30 °C; active cooling is revisited only for a hot-climate site.

## 8. Fire detection and venting (R7, R8)

The electronic part of the detection chain takes about **3.1 s**: a 1 s NTC sample period, two confirming samples and a 0.1 s controller loop, leaving 6.9 s of the 10 s target for the sensor's own thermal lag. A pack's over-temperature fault arrives on CAN as soon as it changes. Opening the bay contactor takes about **0.15 s** (0.10 s decision and 0.05 s drop-out), inside the 1 s target. Smoke transport to the plenum detector and the sensor lag can only be measured, so R7 is **not verifiable at TRL 3**.

The vent path widens from each 36 cm² bay port into a 1,366 cm² plenum, through the two roof fans and out through 240 cm² of slots in the back face of the vent hood, where the fans move air at about 1.0 m/s. Whether this path, two 1.5 mm steel walls and the air gap stop a runaway from spreading for 30 min (R8) can be shown only by a propagation test, which is TRL 4 work and on hold. R8 stays **at risk**.

## 9. Geometry (R2, R11, R13)

The model places the pack's connector face on the cradle at 730 mm and its handle top at 1,105 mm. The door opening is 510 x 150 mm (narrowed from 172 mm to leave room for the door hinges, DKH-DDR-003) against the 393 mm overall pack, leaving 110 mm above the handle for the hand and 30 mm each side of the pack; the rider lifts the pack 19 mm to clear the receptacle. Every operable part lies between 0.73 and 1.10 m (door handles 0.94 to 0.98 m, reader 0.90 to 0.99 m), inside the 0.38 to 1.22 m range: **R11 met**.

The plinth is now flush with the body, so the footprint is 1,000 x 500 mm (door handles add 22 mm at the front); at TRL 2 it was 1,020 x 520 mm, which broke the 1.0 m width limit. The panel's rear edge underside is at 2,214 mm and its front top edge at 2,446 mm; the lowest canopy point over the sidewalk is the rear end of a rail at 2,171 mm (printed by `cad/src/model.py`). **R13 met.**

For R2, each bay builds to SwapCell interface v0.3 without changing it: a blind-mate receptacle with a 10 kΩ coding resistor in the INTERLOCK loop (item W), dock host type 1 in the heartbeat, a class D gravity catch for the pack's latch pawl (item V) and a CAN channel per bay at 250 kbit/s. At 34.1 frames per second one pack loads its channel to 1.8 %; the four SPI CAN controllers need about 17.5 kbit/s of SPI traffic in all. Packs still default to node 0, and v0.3 node numbers 0 to 7 do not remove the need for separate channels, because a pack's node number would have to change at every station. **R2 met by design review.**

For R12, a 64 B log record per swap is 1.28 kB a day, and a list of 10,000 rider tokens at 20 B each is 200 kB, both trivial for the controller's flash and SD card over 24 h offline. Each token entry holds an 8 B hash of the card's identifier, a type (named token or anonymous prepaid card, decided 2026-10-02), whether a pack deposit is held, the prepaid swaps left, an expiry date and flags; no name or contact detail is stored. **R12 met by design review.**

## 10. Mass

*Table 5. Mass of the four-bay station with three packs.*

| Part | Mass (kg) |
| --- | --- |
| Sheet steel, 10.24 m² at 1.5 mm plus 15 % | 138.6 |
| Plinth, 4.0 m of 100 x 50 x 5 mm channel | 29.8 |
| Canopy posts and rails | 21.0 |
| Roof beams and cleats, post base and cap plates, hinges, end clamps, catch brackets | 9.6 |
| Solar panel | 21.0 |
| Chargers (4) | 4.8 |
| Cradles and receptacles (4) | 2.0 |
| Controller, MPPT, grid unit, access panel, fire unit, fans, wiring | 12.0 |
| Packs (3) | 8.6 |
| **Total** | **247** |

The two-bay prototype without packs weighs about **217 kg**, which is used for the wind check. The site pad chosen on 2026-10-02 adds about 1,109 kg of concrete under it (section 11); the trial vermiculite trays add well under 1 kg a bay. The TRL 2 estimate of 150 to 170 kg counted about 8 m² of sheet; the model's bay liners, deck, plenum wall, charger shelf and vent hood bring it to 10.24 m². The roof frame, post plates, hinges and other parts added to make the design buildable (DKH-DDR-003) add 9.6 kg.

## 11. Wind and anchoring (R15)

At a 30 m/s gust the dynamic pressure is 551 Pa. The 1.95 m² panel takes a normal force of 1,615 N, which at 10° of tilt is 280 N sideways and **1,590 N of uplift**, acting 429 mm in front of the cabinet centre; the posts add 158 N and the body 1,075 N of drag. About the rear bottom edge this gives an overturning moment of **2.91 kN·m**, against 0.53 kN·m from the prototype's own weight: a factor of 0.18. Unanchored, the cabinet would tip, and friction alone (215 N) would not stop it sliding either. The TRL 2 note treated the canopy force as horizontal and missed the uplift; the corrected moment is lower than its 3.6 kN·m, but the conclusion stands.

With four M12 anchors 30 mm in from the front and rear edges (and 25 mm in from the ends, where a socket reaches them through capped holes in the floor), each front anchor carries **2.53 kN** of tension, **3.79 kN** with the 1.5 load factor, and each anchor about 0.57 kN of design shear. Each front canopy post pulls up on the roof frame with about 1,251 N, so each post bolts through the roof sheet into a 40 x 40 x 4 mm angle roof beam, which is bolted at each end to the front and back panels (DKH-DDR-003); the posts themselves see only 9.4 MPa in bending (50 x 50 x 3 mm hollow section, 714 mm long). **Anchors and pad (chosen 2026-10-02).** The first pilot is on private ground, so the cabinet gets its own cast pad rather than relying on the host's ground: reinforced concrete 1,400 x 1,100 x 300 mm (about **1,109 kg**), top flush with the ground, the cabinet centred on it, and four M12 x 160 mm stainless wedge anchors at 100 mm embedment (BOM lines 17 and 18). The anchors sit 225 mm from the pad's ends and 330 mm from its front and back edges. Taking the cabinet and pad together about the pad's rear bottom edge, the gust gives an overturning moment of **3.84 kN·m** against **7.15 kN·m** of restoring moment; with a factor of 0.9 on the weight and 1.5 on the wind the ratio is **1.12**, above the 1.0 needed. Friction under the pad (coefficient 0.5) resists 5,708 N against 2,269 N of factored sliding force, and the bearing pressure is only 8.4 kPa. The anchors still carry 3.79 kN of design tension each, which must be at or below the design resistance in the chosen anchor's approval data. A socket reaches each anchor nut through the floor and a 32 mm hole in the plinth's top flange (added on 2026-10-02; the flange had blocked it). **R15 is met** on paper, subject to that confirmation.
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

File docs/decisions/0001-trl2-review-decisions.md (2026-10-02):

---
doc_id: DKH-DDR-001
title: DockHub TRL 2 review decisions
project: DockHub
doc_type: Design decision record
version: "0.3"
status: Draft
date: '2026-10-02'
author: Amish Chadha
license: CERN-OHL-S-2.0
revisions:
- version: "0.1"
  date: '2026-09-25'
  author: Amish Chadha
  change: Record the TRL 2 review items adopted for TRL 3 under Amish's 2026-09-25 instruction, and the items that remain open
- version: "0.2"
  date: '2026-09-25'
  author: Amish Chadha
  change: Recommendations accepted by Amish (DDR-002)
- version: "0.3"
  date: '2026-10-02'
  author: Amish Chadha
  change: "Items 10 and 11 decided by Amish as recommended (DKH-DEC-001)"
---
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

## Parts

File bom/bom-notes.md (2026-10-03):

# BOM notes

All costs are indicative USD prices for a single prototype, not quotes. Suppliers are not yet selected; each line names a supplier type and gives its price basis.

- Line numbers match the exploded view (`media/exploded.png`) and the precis (DKH-PRC-001). Lines 16 to 19 have no callout.
- The BOM is for the first prototype: the cabinet is built for four bays, with bays 1 and 2 fitted (lines 2, 3 and 5 at quantity 2) and bays 3 and 4 closed with blank plates (in line 1). This is DKH-DDR-001 item 1, decided by Amish on 2026-09-25: go with recommendation (DKH-DDR-002).
- Value-engineering target: USD 1,200. Estimated cost of the constructable design: USD 1,519 (USD 319 over the target), checked by `docs/04-calcs/sizing.py` (DKH-CAL-001 section 12). `budget_usd` in `project.yaml` is unchanged.
- Lines 17 and 18 (added 2026-10-02): four M12 stainless wedge anchors (USD 10 each, retail price for approved stainless anchors plus a security nut) and a cast reinforced concrete pad 1,400 x 1,100 x 300 mm (USD 265: 28 bags of 36 kg premix at about USD 6.50, USD 40 of 10 mm bar mesh, USD 25 of formwork and USD 18 of gravel). They are for the first pilot on private ground (decided 2026-10-02) and are sized in DKH-CAL-001 section 11. Without them the estimate is USD 1,214.
- Line 19 (added 2026-10-02) is the vermiculite bay floor tray, a trial option for the propagation trial at about USD 11 a bay (tray about USD 8, vermiculite about USD 3). Its quantity is 0: it is not fitted to the first prototype and not in the total.
- Each further bay (door, compartment, charger) adds USD 112; all four bays fitted cost USD 1,743.
- Line 5 specifies a charger power factor of 0.9 or better; without power factor correction four chargers overload a 120 V 15 A circuit (DKH-CAL-001 section 6). The price assumes this does not cost more; confirm at supplier selection.
- Line 3 carries the SwapCell interface v0.3 receptacle with its 10 kΩ INTERLOCK coding resistor and a class D latch catch.
- SwapCell packs (line 4) are not in the station cost; they are priced once in the SwapCell BOM at about USD 414 each (SWC-CAL-001). One bay is always empty, so the prototype holds one resident pack and a four-bay station three, plus one pack per rider in circulation.
- Mass: 217 kg for the two-bay prototype without packs and 247 kg for four bays with three packs (DKH-CAL-001 section 10); the site pad adds about 1,109 kg of concrete.
- Excluded: electrical connection by an electrician, permits, anonymous prepaid cards (sold by the partner) and the cellular data plan.

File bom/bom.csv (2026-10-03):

item | qty | spec | supplier | unit_cost_usd | make_buy | notes
1 Cabinet body | 1 | Galvanized steel sheet 1.5 mm: laser-cut front panel with bay, service and access openings; back panel and two side panels; roof panel and floor pan with folded flanges; bay deck and charger shelf; all joined with blind rivets. Roof frame of two 40 x 40 x 4 mm steel angle beams with four bolted cleats (weld nuts) under the canopy posts. Powder coat (light color); two blank plates over unfitted bays 3 and 4 | Local sheet metal shop | 260.00 | make | Indicative material and folding cost; built for four bays (DKH-DDR-001 item 1); panels and roof frame as DKH-DDR-003
2 Bay door with solenoid lock | 2 | Steel door plate 172 x 526 x 2 mm with riveted lock tongue and pull handle, stainless piano hinge, 7 x 3 mm EPDM gasket strip, 12 V fail-secure solenoid lock with door switch | Hardware and access-control supplier | 22.00 | buy | Indicative price; bays 1 and 2 fitted in the first prototype; 2 more for the full fit
3 Bay compartment with cradle and receptacle | 2 | Folded steel liner 180 x 358 x 530 mm with top flange and vent port; cradle printed with its guide faces in flame-retardant filament; folded 3 mm steel catch bracket with class D latch catch; SwapCell v0.3 blind-mate receptacle with 10 kOhm INTERLOCK coding resistor; NTC on the receptacle | Local fabricator plus connector supplier | 35.00 | make | Indicative price; mirrors the SwapCell wall dock cradle (interface v0.3 items W and V)
4 SwapCell pack (reference) | 1 | 13S2P 21700, 46.8 V nominal, about 468 Wh, 2.85 kg, 340 x 90 x 80 mm body, 393 mm overall (SwapCell interface v0.3) | SwapCell project | 0.00 | make | Not in station cost; priced once in the SwapCell BOM (about $414 per SWC-CAL-001); one resident pack with two bays fitted (one bay is always empty)
5 Charger | 2 | Certified lithium-ion charger, 54.6 V 5 A CC-CV, about 303 W input, 100 to 240 V AC, power factor 0.9 or better | E-bike parts supplier | 55.00 | buy | Indicative price; switched on its DC side by the controller; power factor to confirm at supplier selection (DKH-CAL-001 R5)
6 Dock controller | 1 | ESP32 with four SPI CAN controllers and transceivers (one CAN channel per bay), four DC contactors or relays rated 60 V DC 10 A, current sensors, LTE-M modem, SD card, DIN box | Electronics distributor | 70.00 | buy | Indicative price; sized for all four bays
7 Access panel | 1 | Vandal-resistant NFC reader, sunlight-readable display, per-bay status lights, buzzer, steel bezel | Electronics distributor | 45.00 | buy | Indicative price
8 Grid input and protection | 1 | DIN enclosure with 30 mA RCBO, one breaker per charger, surge protection device, lockable isolator, cable gland; 120 V or 230 V single phase | Electrical wholesaler | 85.00 | buy | Indicative price; installation by a qualified electrician
9 Fire detection and suppression | 1 | Heat and smoke detector, per-bay NTC sensors (on item 3), small condensed-aerosol fire suppression unit with electrical and thermal trigger | Fire safety supplier | 110.00 | buy | Indicative price; the aerosol unit is kept for the first prototype (decided 2026-10-02); vermiculite bay floors are tested against it in the propagation trial (line 19)
10 Vent plenum and roof vent hood | 1 | Plenum wall of folded 1.5 mm sheet with bay vent ports, vent hood with rear slots and rain lip over two roof fan holes, two 120 mm IP55 fans on 4 mm spacers, intake filter pad in the service door | Local fabricator plus electronics distributor | 45.00 | make | Indicative price
11 Solar panel | 1 | 400 W monocrystalline, about 1,722 x 1,134 x 35 mm, about 21 kg, Vmp about 31 V | Regional solar distributor | 110.00 | buy | Indicative price
12 Canopy frame | 1 | Four 50 x 50 x 3 mm square steel posts welded to 50 x 100 x 8 mm base plates and 6 mm cap plates cut to the 10 degree tilt; two 50 x 40 x 3 mm rails; four solar panel end clamps; eight M10 bolts through the roof into the roof beams | Local fabricator | 70.00 | make | Indicative material cost; end clamps and post plates added for construction (DKH-DDR-003)
13 MPPT solar charge controller | 1 | PV input up to 100 V, programmable lithium profile set to 54.6 V CV, output current limited to 5 A, feeds bay 1 | Solar distributor | 70.00 | buy | Indicative price; bay 1 also keeps its AC charger
14 Plinth and anchor frame | 1 | Steel channel 100 x 50 x 5 mm, mitred and welded into a 1,000 x 500 x 100 mm frame flush with the body, flanges inward; four 14 mm anchor holes in the bottom flange, four 32 mm socket holes over them in the top flange and eight 11 mm body bolt holes; tamper-resistant fixings | Local fabricator | 40.00 | make | Indicative price; the anchors are line 17 and the site pad line 18; 32 mm socket holes in the top flange over the anchors (added 2026-10-02 so a socket reaches the anchor nuts)
15 Service door | 1 | Steel door 920 x 520 x 2 mm with stainless piano hinge, cam lock, 7 x 3 mm EPDM gasket, intake slot and door switch | Local sheet metal shop | 35.00 | make | Indicative price; piano hinge added for construction (DKH-DDR-003)
16 Wiring and hardware | 1 | DC fuse per bay (60 V DC, 1 kA or more breaking capacity), DC cable, ferrules, DIN rail, eight M10 floor bolts, M8 cleat bolts, M5 cradle and lock screws, blind rivets, sealing washers, cable glands, labels | Electrical wholesaler | 50.00 | buy | Indicative price; no exploded-view callout
17 Anchors | 4 | M12 x 160 mm stainless steel (A4) wedge anchor with an ETA or ICC-ES approval for cracked concrete, 100 mm embedment, washer and tamper-resistant nut; design tension resistance in C25/30 concrete of at least 3.8 kN each at 225 mm edge distance, confirmed from the maker's approval data | Fixings supplier | 10.00 | buy | Indicative price (stainless M12 wedge anchors retail at about USD 6 to 10 each, plus a security nut); chosen 2026-10-02 for the first pilot on private ground (DKH-CAL-001 section 11)
18 Concrete pad | 1 | Reinforced concrete pad 1,400 x 1,100 x 300 mm (0.46 m3, about 1,110 kg), top flush with the ground, on 100 mm of compacted gravel; C25/30 from 28 bags of 36 kg (80 lb) premixed concrete; 10 mm bar mesh at 200 mm top and bottom; timber formwork; cabinet centred on it | Builders merchant | 265.00 | make | Indicative price: 28 bags at about USD 6.50 (USD 182), mesh USD 40, formwork USD 25, gravel USD 18; cast by the build team at the host site. Sized so the cabinet and pad stand at a 30 m/s gust without relying on the host's ground (DKH-CAL-001 section 11); a host slab can replace it only if an engineer confirms it
19 Vermiculite bay floor (trial option) | 0 | Per bay: 1 mm stainless steel tray 175 x 168 x 20 mm, corners folded and riveted, riveted to the liner floor in front of the cradle, filled to 2 mm below its rim with exfoliated vermiculite (about 0.5 L) | Local fabricator plus garden or insulation supplier | 11.00 | make | Trial option for the propagation trial (decided 2026-10-02), not fitted to the first prototype and not in its cost; indicative price: tray about USD 8, vermiculite about USD 3 per bay (an 8 to 10 L bag at about USD 12 fills all four)

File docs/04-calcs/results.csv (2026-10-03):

id | value | target | status
R16 | $1,519 with 2 of 4 bays fitted, anchors and pad included ($1,743 with 4) | $1,200, packs excluded (two bays fitted, DKH-DDR-001) | Not met
R8 | Two 1.5 mm steel walls and a gap between packs; propagation needs a test | No spread for 30 min | At risk (not verifiable at TRL 3)
R9 | Full-rate charging up to about 29 to 39 degC ambient; cold-soaked packs start only above about -1 degC; charge window enforced by pack and controller | Full-rate charging up to about 30 degC; cold-soak limit near -1 degC stated (restated 2026-10-02) | At risk (warmest bay may pause just under 30 degC)
R7 | Electronic latency 3.1 s; contactor 0.15 s; vent path to the roof louver by design | Detect in 10 s; contactor in 1 s | Not verifiable at TRL 3
R14 | All parts through the service door or bay door with hand tools | 15 min per part | Not verifiable at TRL 3
R1 | 31 s task analysis | 60 s or less | Met
R2 | Interface v0.3: coded INTERLOCK receptacle, dock host type 1, class D catch, one CAN channel per bay | Build to the SwapCell interface, no change | Met (design review)
R3 | 20 to 80 % in 1.2 h; full in 2.3 h | 1.5 h; 2.5 h | Met
R4 | 4 bays: 20 of 20 served, longest wait 4 min; ceiling 36 a day (55 at 80 % release). 2-bay prototype: 9 of 20 served | 20 a day from 4 bays | Met (4 bays)
R5 | 1.25 kW; 11.0 A at 120 V with PF 0.95 (17.2 A at PF 0.6) | 1.5 kW; one 120 V 15 A or 230 V 10 A circuit | Met (PF 0.9 or better chargers)
R6 | 9.3 % of charging energy (0.74 of 1.38 kWh used); 11.4 % with solar steering, which turns 1 rider away; 16.1 % if the MPPT is switched to the flattest pack (TRL 4 trial) | About 9 % with normal routing (restated 2026-10-02, DKH-DEC-001) | Met (thin margin)
R10 | 1.5 mm steel, fail-secure locks, anchored plinth, token plus returned pack | Security features | Met (design review)
R11 | Operable parts 0.73 to 1.10 m | 0.38 to 1.22 m | Met
R12 | 1.28 kB of log a day; offline token list 200 kB | No cameras; 24 h offline | Met (design review)
R13 | 1.0 x 0.5 m; canopy lowest point over the sidewalk 2.17 m | 1.0 x 0.6 m; 2.1 m | Met
R15 | Overturning 2.9 kN m against 0.53 kN m self-weight; four M12 anchors at 3.8 kN design tension into a 1109 kg pad, equilibrium factor 1.12 | Upright at a 30 m/s gust | Met (anchor rating to confirm from the maker's data)

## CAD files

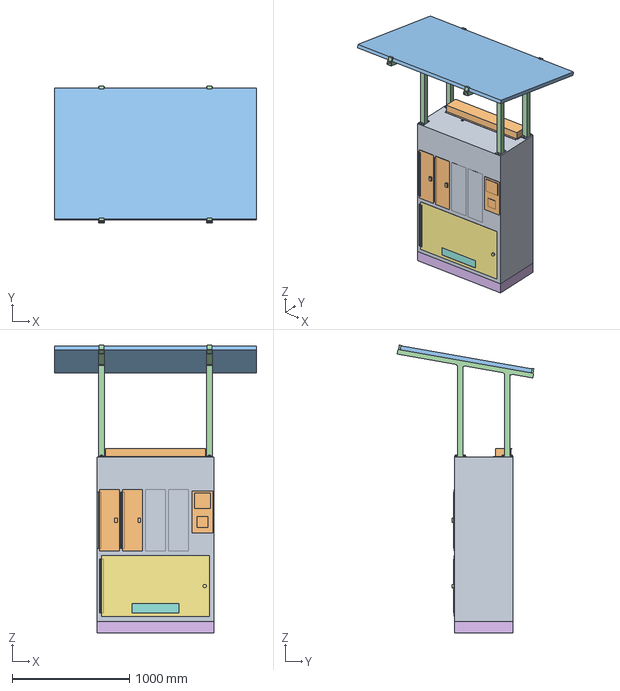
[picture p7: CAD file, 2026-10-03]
cad/step/dockhub-assembly.step
1722.0 x 1165.0 x 2452.2 mm

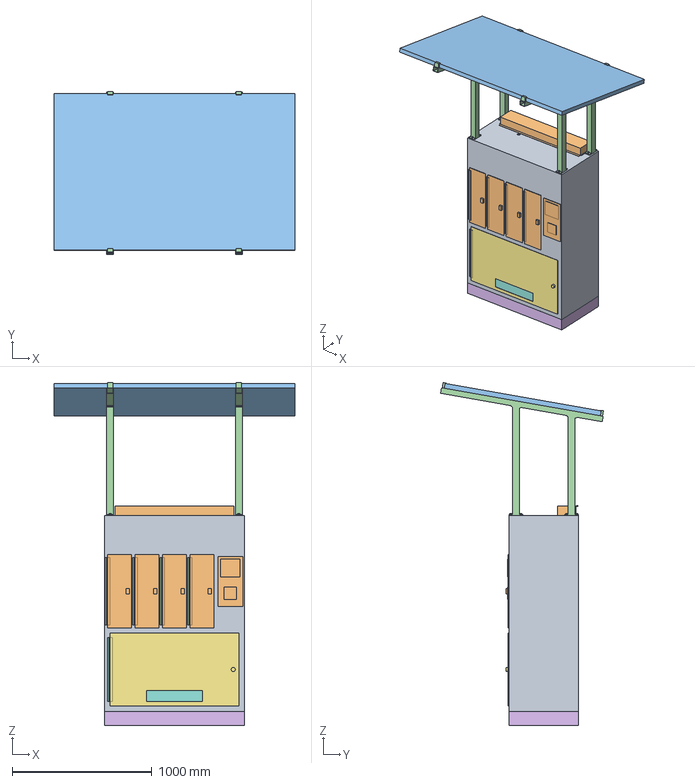
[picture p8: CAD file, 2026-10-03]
cad/step/dockhub-assembly-4-bays.step
1722.0 x 1165.0 x 2452.2 mm

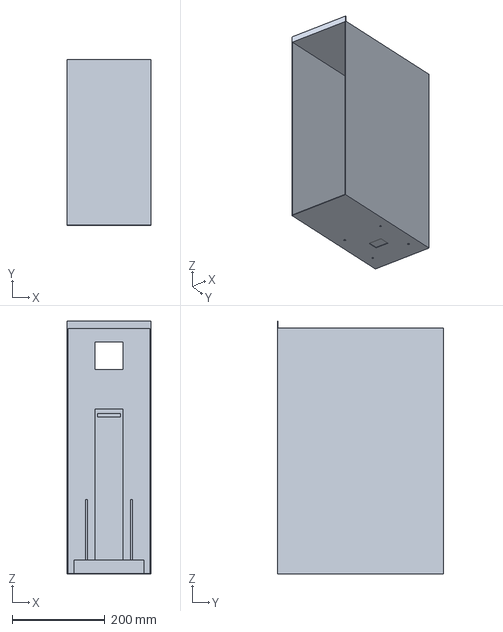
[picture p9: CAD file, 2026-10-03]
cad/step/dockhub-bay.step
180.0 x 358.5 x 545.0 mm

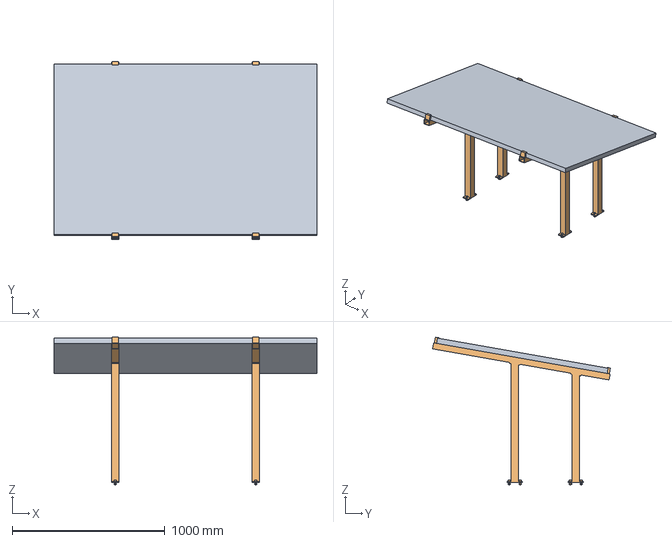
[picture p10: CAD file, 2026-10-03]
cad/step/dockhub-canopy.step
1722.0 x 1165.0 x 967.7 mm

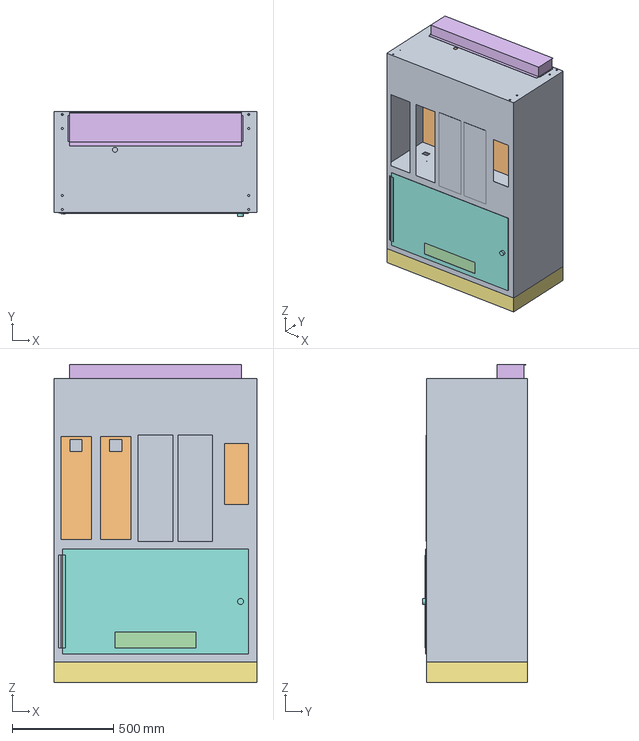
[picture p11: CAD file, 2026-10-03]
cad/step/dockhub-cabinet.step
1000.0 x 520.0 x 1570.0 mm

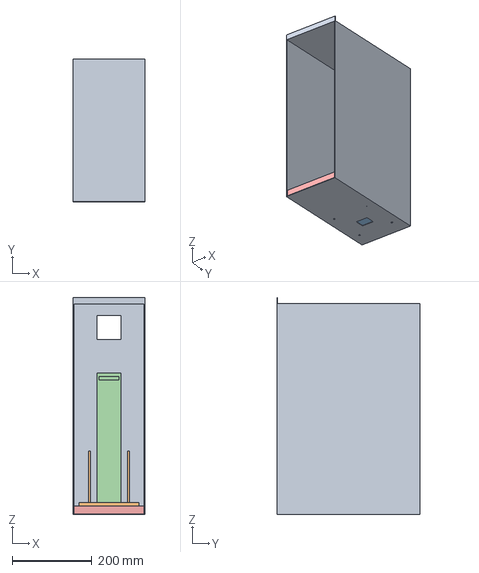
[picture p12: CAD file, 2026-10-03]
cad/step/dockhub-bay-vermiculite.step
180.0 x 358.5 x 545.0 mm

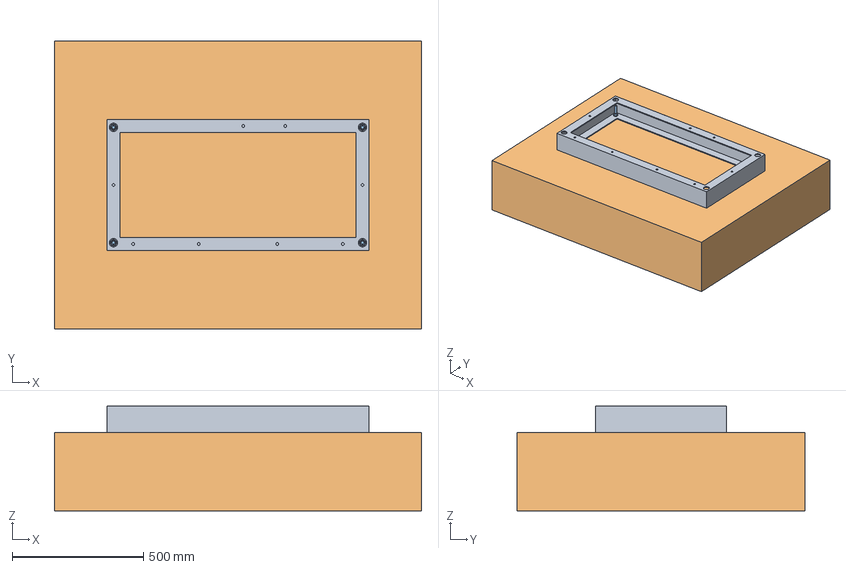
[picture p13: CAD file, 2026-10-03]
cad/step/dockhub-site-pad.step
1400.0 x 1100.0 x 400.0 mm

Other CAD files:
cad/stl/dockhub-assembly-4-bays.stl
cad/stl/dockhub-assembly.stl
cad/stl/dockhub-bay-vermiculite.stl
cad/stl/dockhub-bay.stl
cad/stl/dockhub-cabinet.stl
cad/stl/dockhub-canopy.stl
cad/stl/dockhub-site-pad.stl

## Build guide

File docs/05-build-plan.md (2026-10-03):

---
doc_id: DKH-BLD-001
title: DockHub prototype build plan
project: DockHub
doc_type: Build plan
version: "0.4"
status: Draft
date: '2026-10-02'
author: Amish Chadha
license: CERN-OHL-S-2.0
revisions:
  - version: "0.1"
    date: '2026-10-01'
    author: Amish Chadha
    change: First build plan, with pictures by component and step; design made constructable (DKH-DDR-003, Draft)
  - version: "0.2"
    date: '2026-10-01'
    author: Amish Chadha
    change: Budget treated as a value-engineering target; cross-references updated
  - version: "0.3"
    date: '2026-10-02'
    author: Amish Chadha
    change: "Safety stop S7: first site on private property with an existing single-phase circuit (DKH-DEC-001)"
  - version: "0.4"
    date: '2026-10-02'
    author: Amish Chadha
    change: "Approved follow-ups: socket holes in the plinth top flange; anchors and site pad chosen (section 9, DKH-DWG-120); vermiculite floor tray as a trial option (DKH-DWG-119)"
---

# DockHub prototype build plan

**Plan, not yet built.** How to build the first proof-of-concept prototype, component by component. Building and testing to it is TRL 4 work. Decisions still to be made are kept in the design decisions register ([docs/06-design-decisions.md](06-design-decisions.md)), not here.

## 1. What you are building

Figure 1. Every component, pulled apart and numbered in build order

*Figure 1. Every component pulled apart and numbered in build order. The shell is pulled apart in place; the parts that go inside it are lined up on the right.*

The prototype is the full DockHub cabinet, 1,000 mm wide, 500 mm deep and 1,500 mm tall to the roof, with its solar canopy on top, built for four bays with bays 1 and 2 fitted and bays 3 and 4 closed by blank plates. The cabinet is a shell of 1.5 mm galvanized steel panels with folded edges, joined with blind rivets, standing on a welded steel channel plinth. Inside are a charger shelf, a bay deck, a plenum wall at the back, two steel bay liners with printed cradles, and the electrical boxes on the back wall. A roof frame of two steel angles carries the four canopy posts, and two rails on the posts carry the 400 W panel. Figure 1 shows the 23 components in the order they are fitted. The made parts, each with its own making sketch, are the plinth, six shell panels, the shelf, the deck, the plenum wall, the liners, the cradles, the catch brackets, the roof beams, the vent hood, the doors and blank plates, the service door, the posts and the rails. The bought parts are chargers, controller, MPPT controller, grid unit, fire unit and detector, fans, receptacles, locks, access panel and solar panel. The work is sheet metal cut and folded at a sheet metal shop (or on a 1.5 m folder), drilling and blind riveting, a little welding of channel, tube and plate, two 3D prints, and bolting bought units in place. The parts cost about $1,214 from the bill of materials, packs and site works not included.

> **Safety:** The finished cabinet stores and charges lithium-ion packs of about 468 Wh each from mains power, and weighs about 217 kg before packs. No pack goes into it, and no mains supply is connected, until the safety stops of section 6 are passed. All mains wiring is done or checked by a qualified electrician. Cut sheet edges are sharp: deburr them and wear cut-resistant gloves. Welding and cutting galvanized steel gives off zinc fumes: grind the zinc off the weld area and weld with extraction or outdoors. Lift the cabinet with equipment, never by hand.

## 2. What changed to make it buildable

The concept showed what DockHub does; parts of it could not be made, fixed or put together as drawn. Each change below keeps what the station does, and all of them are recorded in decision record DKH-DDR-003, open for Amish's review.

*Table 1. Changes from the concept.*

| Component | The concept had | The buildable design has | Why |
| --- | --- | --- | --- |
| Cabinet body | One closed steel box with no joints | Six panels with folded flanges (Figures 4 to 7, 16, 19), joined with blind rivets; the front panel is laser cut with all its openings | A sheet metal shop can make it and two people can put it together |
| Roof frame | Named in the bill of materials but not drawn; the canopy posts stood on the 1.5 mm roof sheet | Two 40 x 40 x 4 mm angle beams under the post lines, bolted through cleats to the front and back panels (Figures 17, 18) | Each front post pulls up with about 1.25 kN in a 30 m/s gust; the sheet alone cannot take it |
| Canopy | Posts stopped 5 mm under the rails, the rails 2 mm under the panel, and nothing held the panel | Posts on welded base and cap plates, the cap cut to the 10° slope; rails 1,174 mm long; four end clamps on the panel frame (Figures 26 to 29) | Every joint touches and is bolted; the clamps hold a bought panel without drilling it |
| Plenum wall and vent | A 10 mm slab with no vent ports; fans 120 mm across under an 80 mm louver, with no hole in the roof | A 1.5 mm folded wall with a port behind each bay; two 110 mm roof holes; a folded vent hood with twelve slots in its back face (Figures 10, 20, 21) | Gas and warm air now have a path out, still to the back and away from the rider |
| Bay doors | 172 mm doors hung 2 mm in front of 172 mm openings, with no hinge or gasket land | Openings 150 mm wide; 2 mm doors 172 x 526 mm on piano hinges, closing on an EPDM gasket; the lock tongue on the door enters a solenoid lock on the liner wall (Figures 22, 23) | Leaves 24 mm between doors for the hinge and an 11 mm overlap for the gasket; the pack still has 30 mm each side |
| Cradle and catch | The receptacle and the cradle occupied the same space; guides and catch post stood unattached | One printed cradle with its guides, the receptacle in a pocket underneath, a folded steel catch bracket standing in a slot and screwed to the liner (Figures 13 to 15) | Every part is held and the receptacle fits where the pack's plug lands |
| Liners, deck, shelf | Floated, with no fixing; the charger rack was a 10 mm plate | Folded sheet with flanges riveted to the panels; liners riveted to the front panel and the plenum wall (Figure 12) | Everything inside is fixed to the shell |
| Electrical boxes, fire unit | Floated 8 to 40 mm off the walls | Screwed to the back panel; the aerosol unit on two straps; the detector under the roof | Every unit has a wall to fix to |
| Plinth and anchors | A solid 60 mm ring; anchors under boxes where no tool could reach them | Welded 100 x 50 x 5 mm channel frame; eight M10 floor bolts; anchors 25 mm from the ends, reached through capped holes in the floor (Figure 3) | A tool reaches every anchor nut with the cabinet built |
| Service door | 960 mm opening leaving no land for a hinge | 900 x 500 mm opening; 920 x 520 mm door on a piano hinge with gasket, cam lock and filtered intake slot (Figures 24, 25) | Room for the hinge and the gasket all round |

## 3. Making the components

Make and check each component before the assembly step that needs it. Sizes are in millimetres. "Left" and "right" are as seen standing in front of the cabinet, facing the doors. Heights are from the ground under the plinth unless a step says otherwise; sideways positions are from the cabinet's centre line. Workshop tolerance is 1 mm on sheet parts and 0.5 mm on hole positions unless a step says otherwise; drawings do not carry tolerances before TRL 4. Rivets are 4 mm blind rivets in 4.1 mm holes at about 100 mm pitch, 12 mm in from the edge, drilled through both parts at assembly.

### 3.1 Plinth

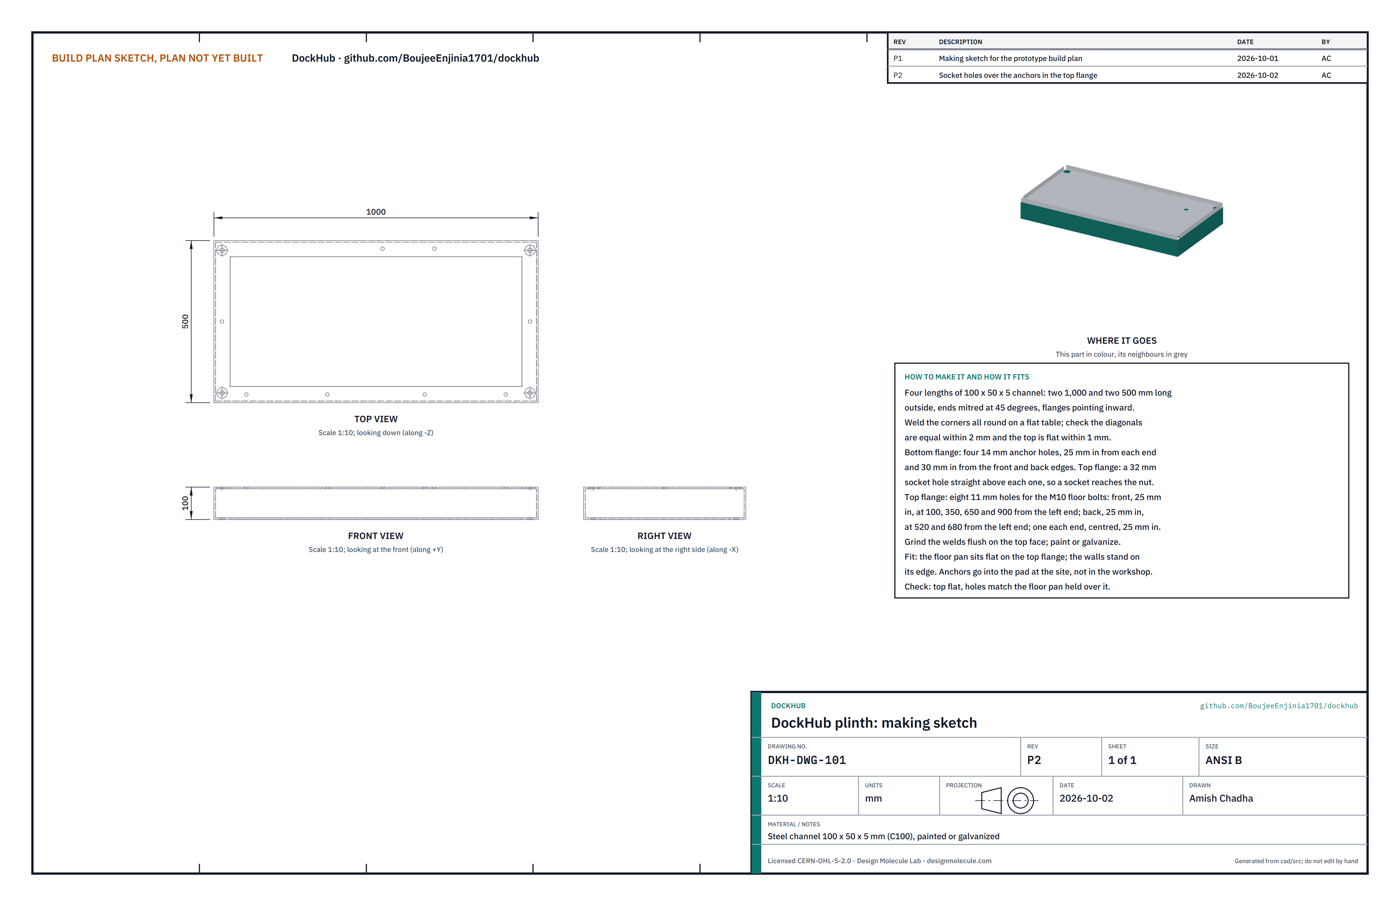
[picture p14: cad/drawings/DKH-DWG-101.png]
Figure 2. Making sketch of the plinth


*Figure 2. Plinth making sketch (DKH-DWG-101).*

**What it is and what it is made from.** The steel frame the cabinet stands on and is anchored through. Steel channel 100 x 50 x 5 mm, painted or galvanized after welding.

**How to make it.**

1. Cut two lengths of 1,000 mm and two of 500 mm, outside measurements, ends mitred at 45°, so that the flanges point inward.
2. Lay them on a flat table, clamp, check the diagonals are equal within 2 mm, and weld each corner all round.
3. In the bottom flange, drill four 14 mm anchor holes, 25 mm in from each end and 30 mm in from the front and back edges. In the top flange, straight above each anchor hole, cut a 32 mm socket hole so that a socket can reach the anchor nut from above.
4. In the top flange, drill eight 11 mm holes for the floor bolts: along the front, 25 mm in, at 100, 350, 650 and 900 mm from the left end; along the back, 25 mm in, at 520 and 680 mm from the left end; and one at each end, 25 mm in, centred front to back.
5. Grind the welds flush on the top face, clean off spatter, and paint or galvanize.

**How it fits the parts next to it.** The floor pan sits flat on the top flange and is held by eight M10 bolts, heads inside the cabinet and nuts under the top flange. At the site, four M12 stainless wedge anchors go through the bottom flange into the concrete pad (section 9); inside the cabinet a socket on an extension reaches each anchor nut through a capped 40 mm hole in the floor and the 32 mm hole in the plinth's top flange:

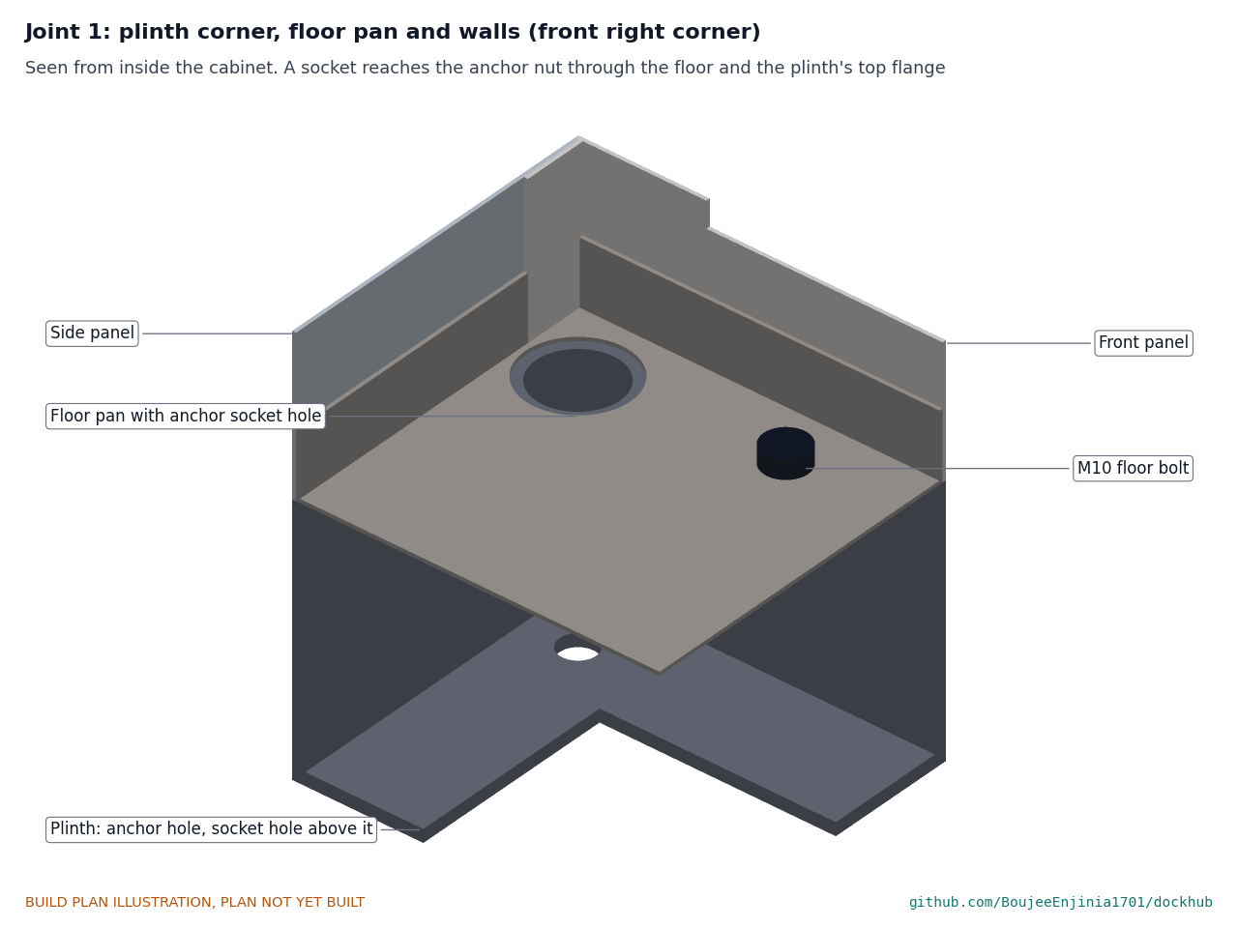
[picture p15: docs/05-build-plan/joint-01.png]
Figure 3. Joint 1: plinth corner, floor pan and walls


*Figure 3. The front right corner seen from inside: the floor pan on the plinth, a floor bolt, and the socket holes in the floor and the plinth's top flange over the anchor hole.*

**Check before moving on.** The top is flat within 1 mm; the diagonals match within 2 mm; held over the floor pan, every bolt hole lines up.

### 3.2 Floor pan

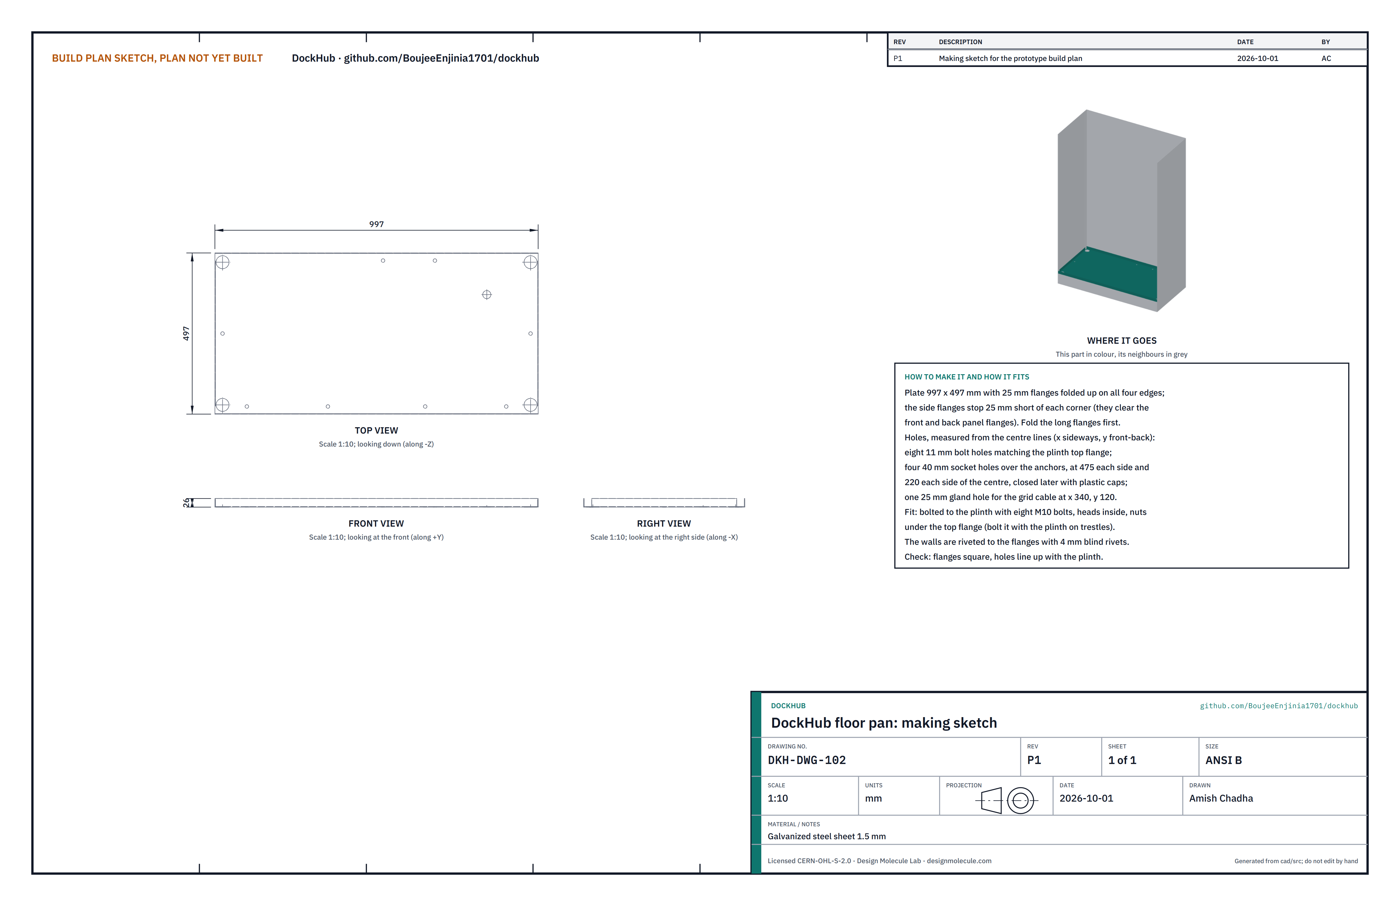
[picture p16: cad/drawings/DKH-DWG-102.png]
Figure 4. Making sketch of the floor pan


*Figure 4. Floor pan making sketch (DKH-DWG-102).*

**What it is and what it is made from.** The floor of the cabinet, which the walls stand on. Galvanized steel sheet 1.5 mm.

**How to make it.**

1. Cut a plate 997 x 497 mm with a 25 mm flange on every edge, and cut the side flanges 25 mm short at each end (corner reliefs), so they clear the flanges of the front and back panels.
2. Fold the long flanges up 90°, then the short ones.
3. Drill eight 11 mm bolt holes through the plate to match the plinth: hold the pan on the plinth and drill through.
4. Cut four 40 mm socket holes over the anchors, 475 mm each side of the centre and 220 mm in front of and behind the centre, and one 25 mm hole for the grid cable gland, 340 mm right of centre and 120 mm behind it.

**How it fits the parts next to it.** It sits on the plinth (Figure 3). The walls stand on the floor plate's edges, outside its flanges, and are riveted through the flanges.

**Check before moving on.** The flanges are square to the plate and the bolt holes line up with the plinth.

### 3.3 Back panel

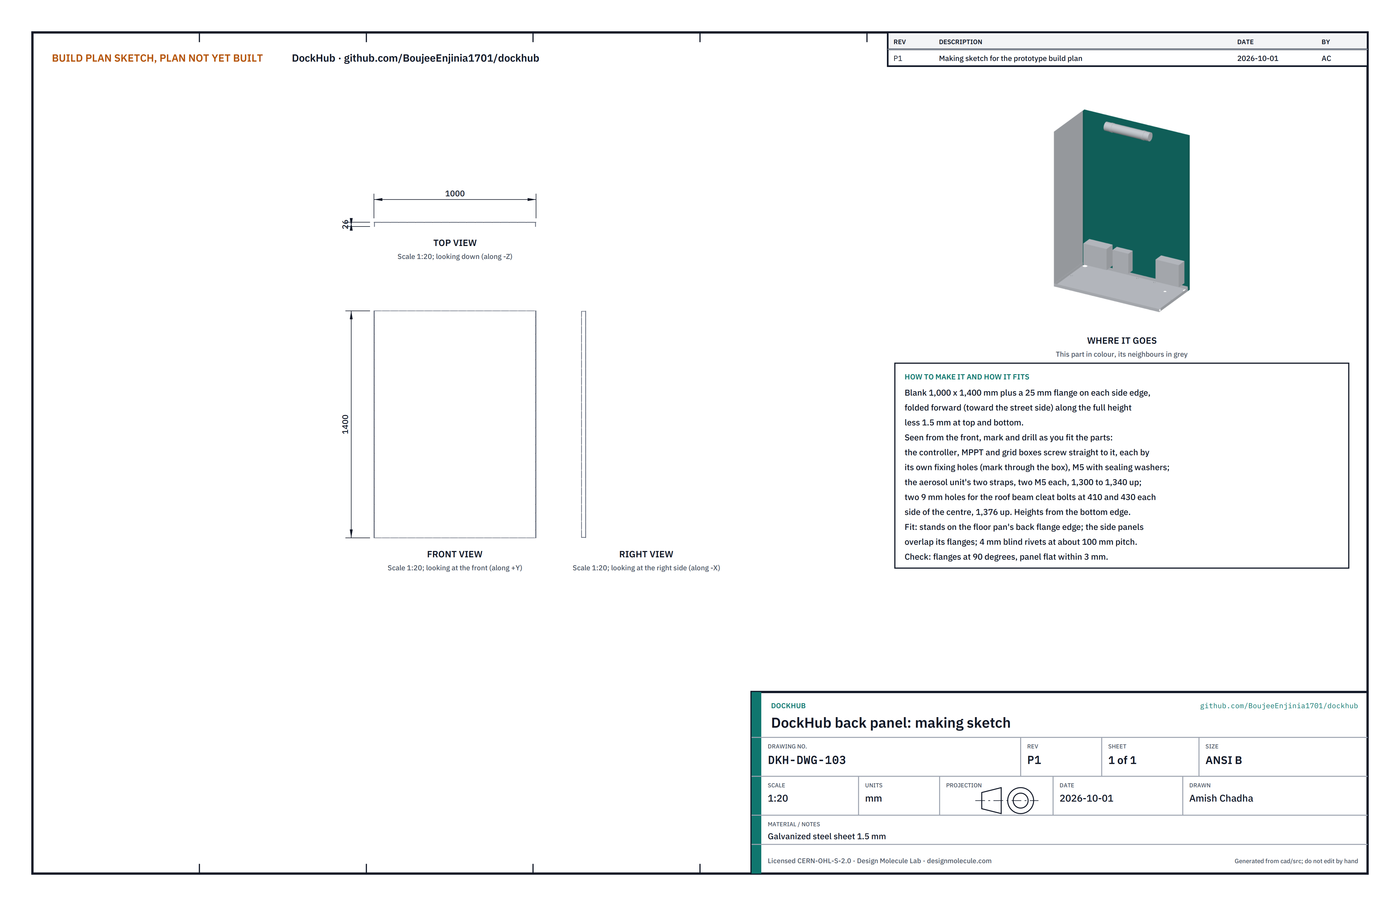
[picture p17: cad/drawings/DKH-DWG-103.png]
Figure 5. Making sketch of the back panel


*Figure 5. Back panel making sketch (DKH-DWG-103).*

**What it is and what it is made from.** The back wall of the cabinet, which also carries the electrical boxes and the fire unit. Galvanized steel sheet 1.5 mm.

**How to make it.**

1. Cut a blank 1,000 x 1,400 mm with a 25 mm flange on each side edge, the flanges 1.5 mm short of the top and bottom edges.
2. Fold both side flanges 90° forward, toward the street side.
3. Leave the box and strap holes until step 4 of section 4, so they are marked through the parts themselves. Heights on the panel are from its bottom edge: the aerosol unit's strap screws go 1,300 to 1,340 mm up, and the roof cleat bolts two 9 mm holes 410 and 430 mm each side of the centre, 1,376 mm up (drilled in step 15).

**How it fits the parts next to it.** It stands on the floor pan's back edge, outside the floor flange; the side panels overlap its side flanges. All joints are blind rivets.

**Check before moving on.** Flanges at 90°, the panel flat within 3 mm.

### 3.4 Side panels (make 2)

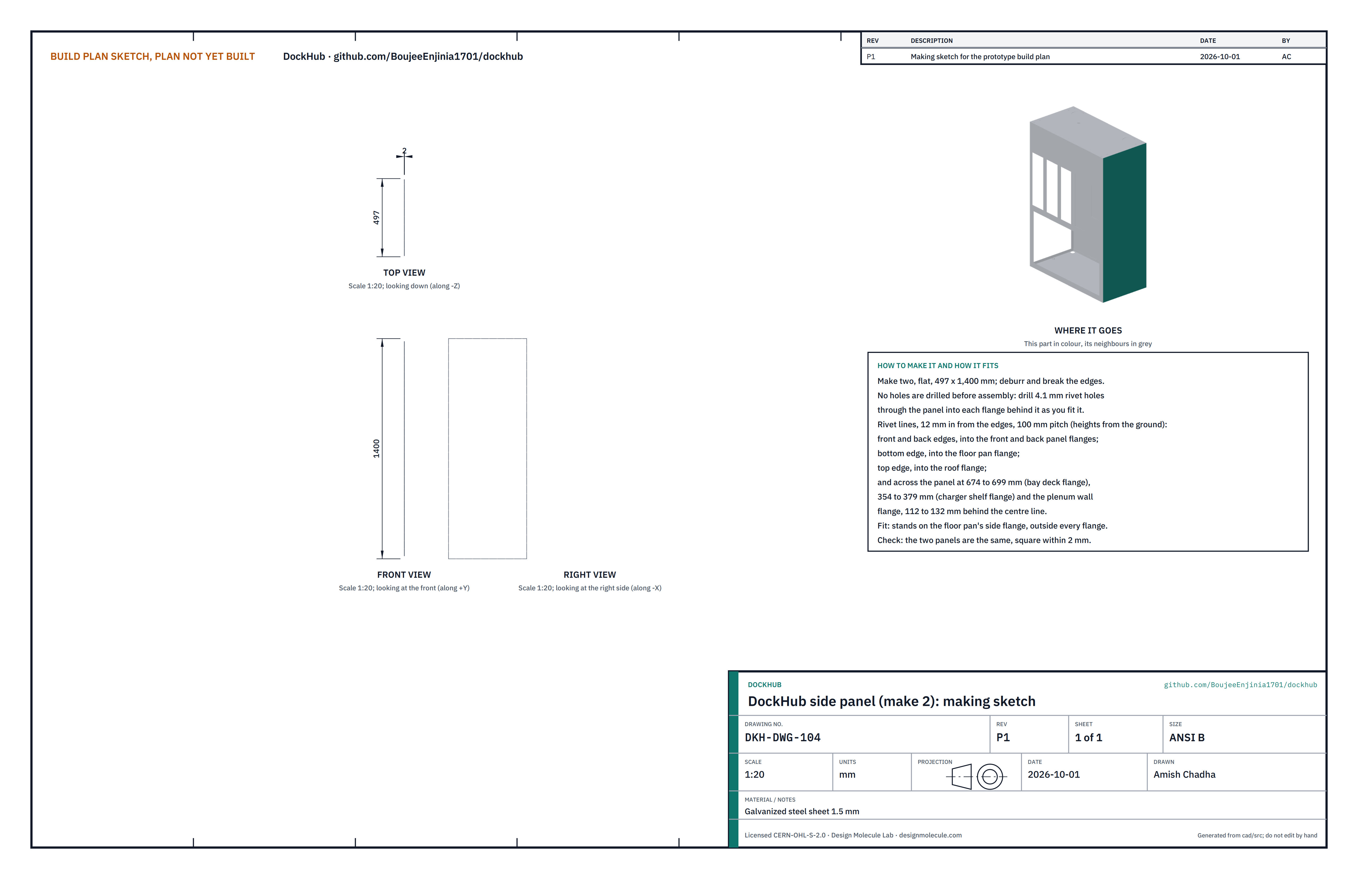
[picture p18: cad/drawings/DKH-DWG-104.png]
Figure 6. Making sketch of the side panel


*Figure 6. Side panel making sketch (DKH-DWG-104).*

**What it is and what it is made from.** The two flat ends of the cabinet. Galvanized steel sheet 1.5 mm, 497 x 1,400 mm.

**How to make it.**

1. Cut two panels 497 x 1,400 mm and deburr the edges.
2. Drill no holes yet: every rivet hole is drilled through the panel into the flange behind it at assembly. The rivet lines are 12 mm in from the front, back, bottom and top edges, and across the panel where the bay deck flange (674 to 699 mm above the ground), the charger shelf flange (354 to 379 mm) and the plenum wall flange (112 to 132 mm behind the centre line) lie against it.

**How it fits the parts next to it.** Each side panel stands on the floor pan's edge, outside every flange that meets it:

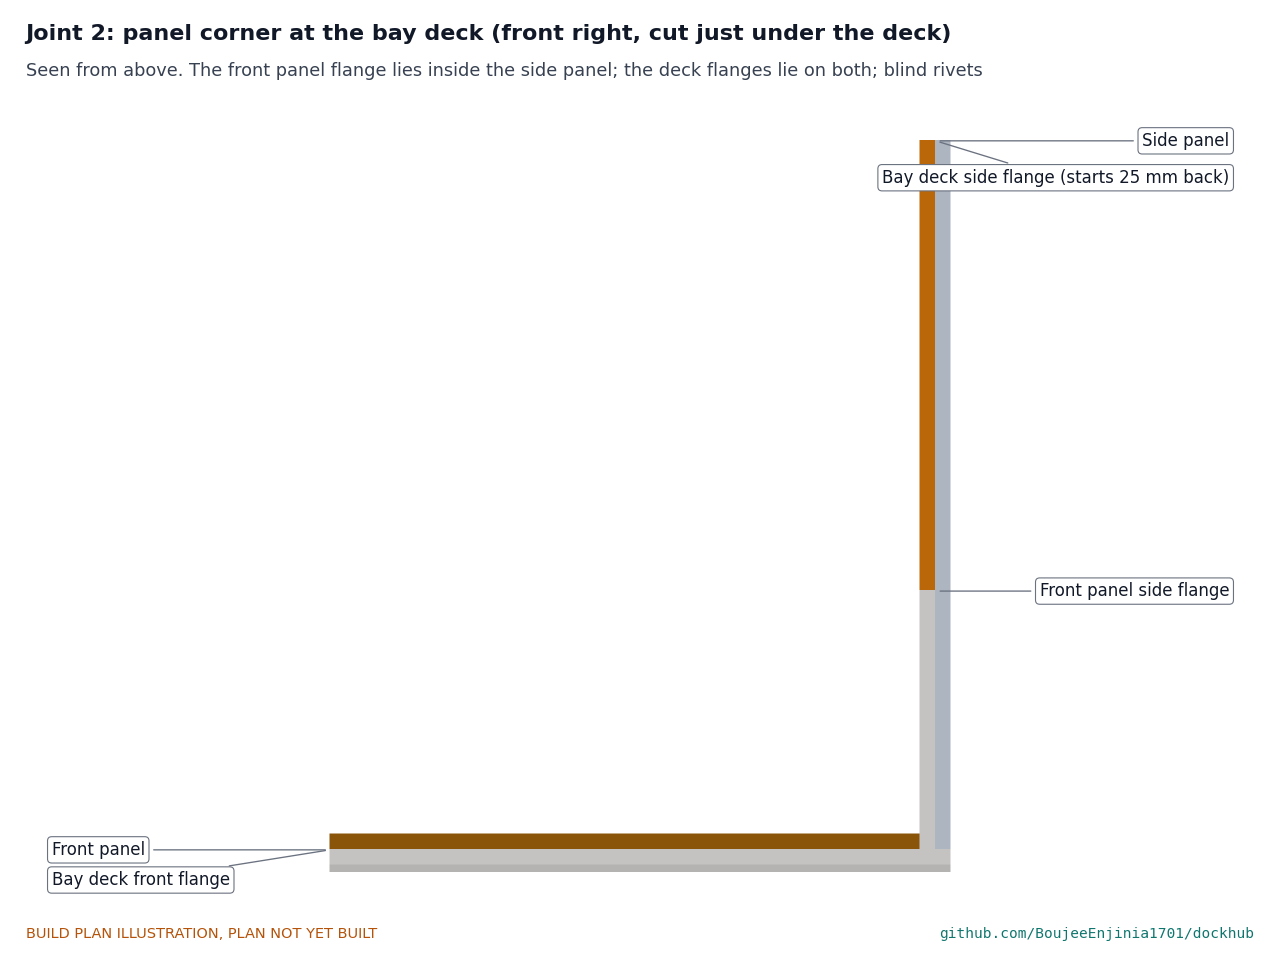
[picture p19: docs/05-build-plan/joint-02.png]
Figure 7. Joint 2: panel corner at the bay deck


*Figure 7. The front right corner, cut just under the bay deck and seen from above: the front panel's flange lies inside the side panel, the deck's flanges lie on both, and the deck's side flange starts 25 mm back to clear the front panel flange.*

**Check before moving on.** The two panels are the same and square within 2 mm.

### 3.5 Charger shelf

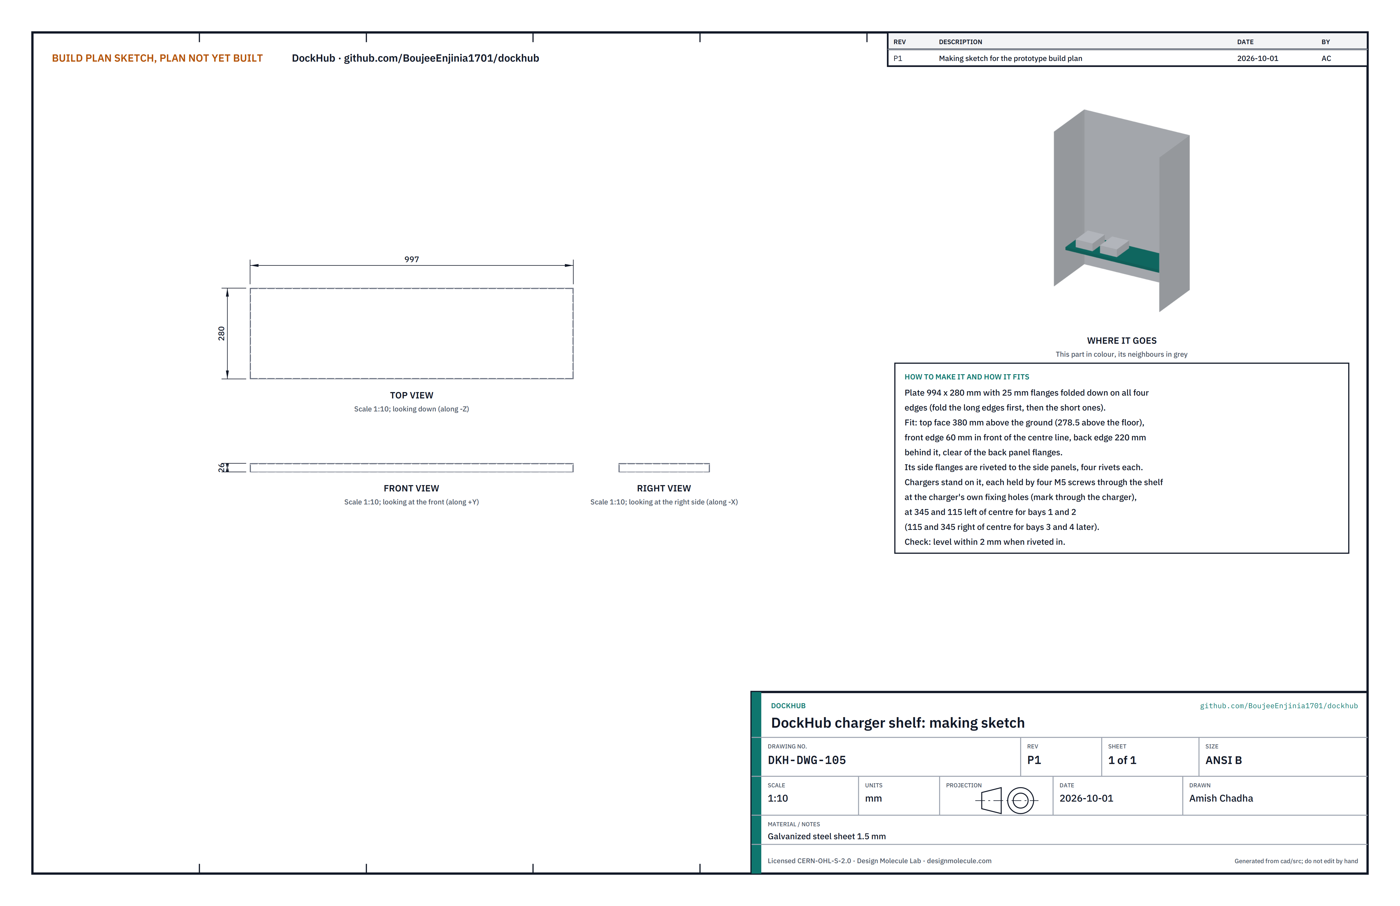
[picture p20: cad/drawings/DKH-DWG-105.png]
Figure 8. Making sketch of the charger shelf


*Figure 8. Charger shelf making sketch (DKH-DWG-105).*

**What it is and what it is made from.** The shelf in the technical compartment that the chargers stand on. Galvanized steel sheet 1.5 mm.

**How to make it.**

1. Cut a plate 994 x 280 mm with a 25 mm flange on every edge, corners relieved.
2. Fold all four flanges down 90°, the long edges first.

**How it fits the parts next to it.** Its top face is 380 mm above the ground, from 60 mm in front of the centre line to 220 mm behind it, clear of the back panel's flanges. Its side flanges are riveted to the side panels, four rivets each. Each charger stands on it on four M5 screws through the shelf at the charger's own fixing holes, bay 1's charger centred 345 mm and bay 2's 115 mm left of centre.

**Check before moving on.** Level within 2 mm once riveted.

### 3.6 Bay deck

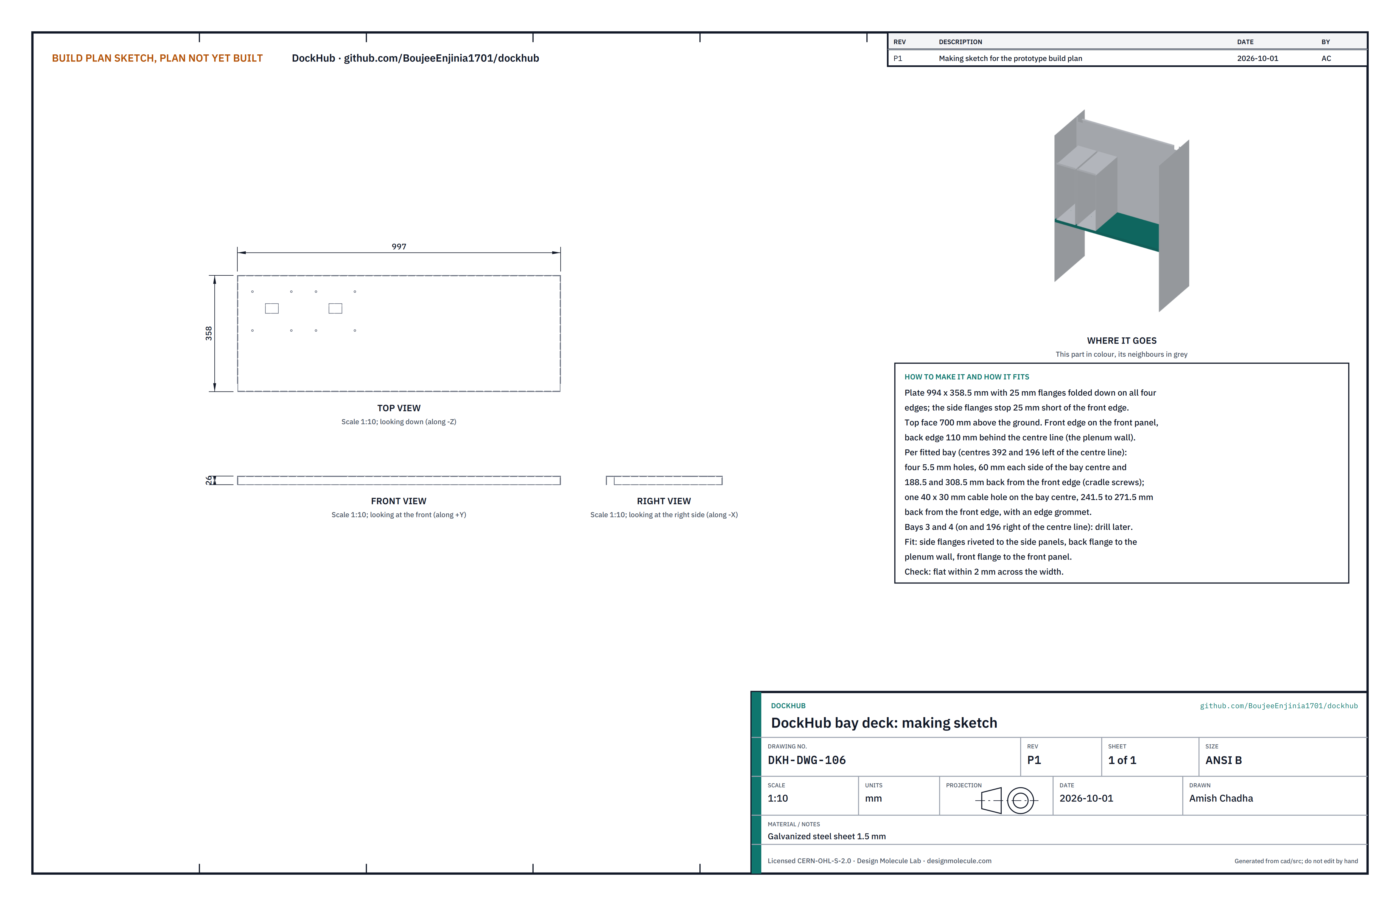
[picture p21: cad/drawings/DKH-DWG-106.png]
Figure 9. Making sketch of the bay deck


*Figure 9. Bay deck making sketch (DKH-DWG-106).*

**What it is and what it is made from.** The floor of the bay row, which the liners stand on. Galvanized steel sheet 1.5 mm.

**How to make it.**

1. Cut a plate 994 x 358.5 mm with a 25 mm flange on every edge; cut the side flanges 25 mm short at the front.
2. Fold all four flanges down 90°.
3. For each fitted bay (bay 1 centred 392 mm left of the centre line, bay 2 196 mm left): drill four 5.5 mm holes 60 mm each side of the bay centre, 188.5 and 308.5 mm back from the front edge, for the cradle screws; and cut a 40 x 30 mm cable hole on the bay centre, 241.5 to 271.5 mm back from the front edge, and fit an edge grommet. Drill bays 3 and 4 (on the centre line and 196 mm right) when they are fitted.

**How it fits the parts next to it.** Its top face is 700 mm above the ground; its front edge meets the front panel and its back edge stands 110 mm behind the centre line. Its side flanges are riveted to the side panels, its back flange to the plenum wall and its front flange to the front panel.

**Check before moving on.** Flat within 2 mm across the width.

### 3.7 Plenum wall

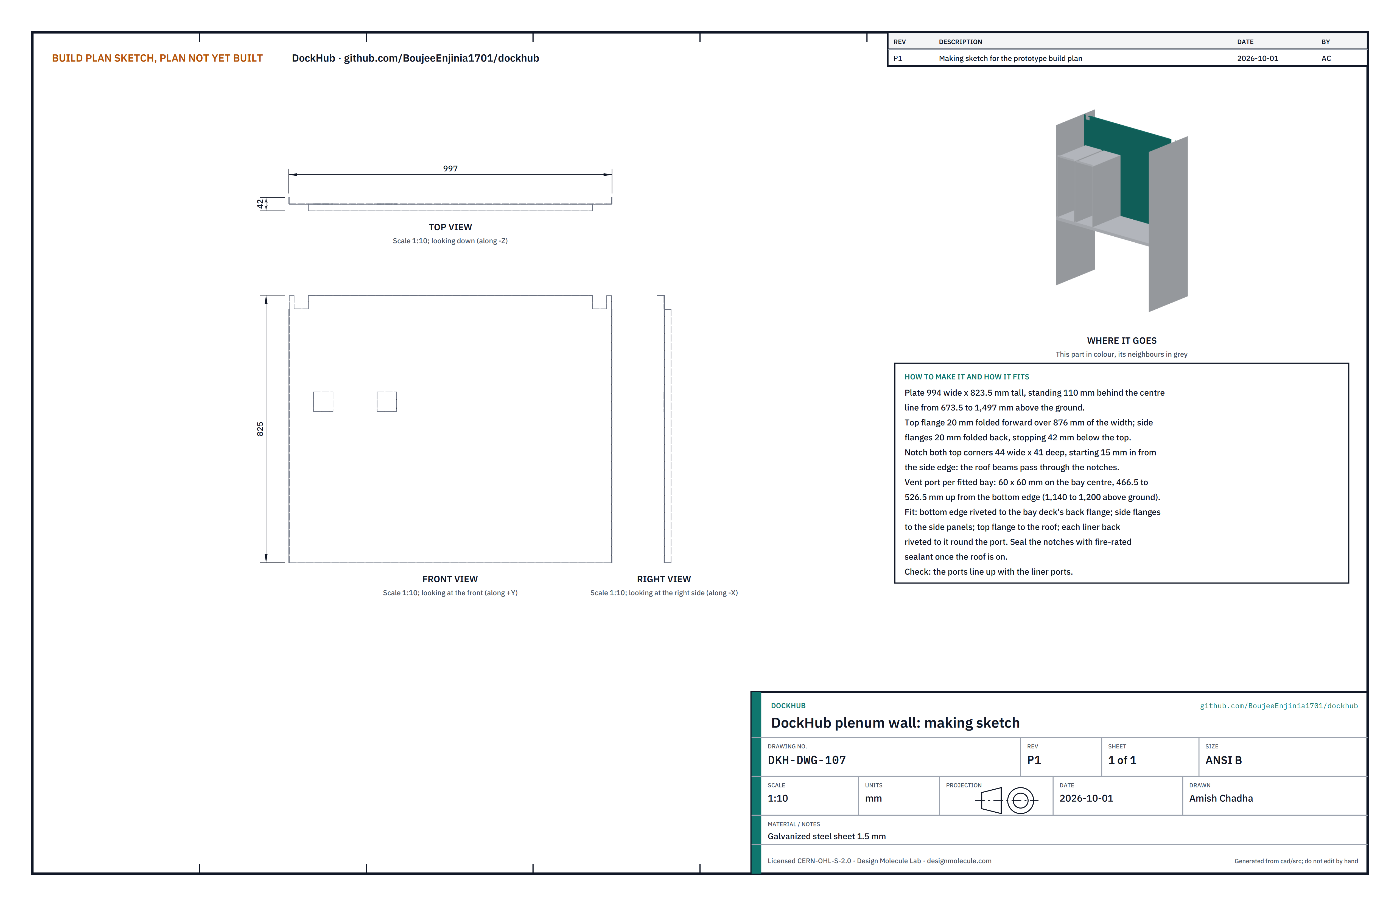
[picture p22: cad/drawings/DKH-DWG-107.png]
Figure 10. Making sketch of the plenum wall


*Figure 10. Plenum wall making sketch (DKH-DWG-107).*

**What it is and what it is made from.** The wall behind the bays. The space between it and the back panel is the plenum: charger heat rises up it, and any gas from a bay goes into it through the bay's vent port and out through the roof fans. Galvanized steel sheet 1.5 mm.

**How to make it.**

1. Cut a plate 994 mm wide and 823.5 mm tall, with a 20 mm flange along the top over the middle 876 mm and a 20 mm flange on each side edge that stops 42 mm below the top.
2. Notch both top corners 44 mm wide and 41 mm deep, starting 15 mm in from the side edge: the roof beams pass through these notches.
3. Fold the top flange forward (toward the bays) and the side flanges back.
4. Cut a 60 x 60 mm vent port for each fitted bay, on the bay centre, 466.5 to 526.5 mm up from the bottom edge (1,140 to 1,200 mm above the ground).

**How it fits the parts next to it.** It stands 110 mm behind the centre line from 673.5 to 1,497 mm above the ground. Its bottom edge overlaps the bay deck's back flange and is riveted to it; its side flanges are riveted to the side panels and its top flange to the roof. Each liner's back is riveted to it round the port (Figure 12). Once the roof is on, seal the beam notches with fire-rated sealant.

**Check before moving on.** The ports line up with the liner ports.

### 3.8 Bay liners (make 2)

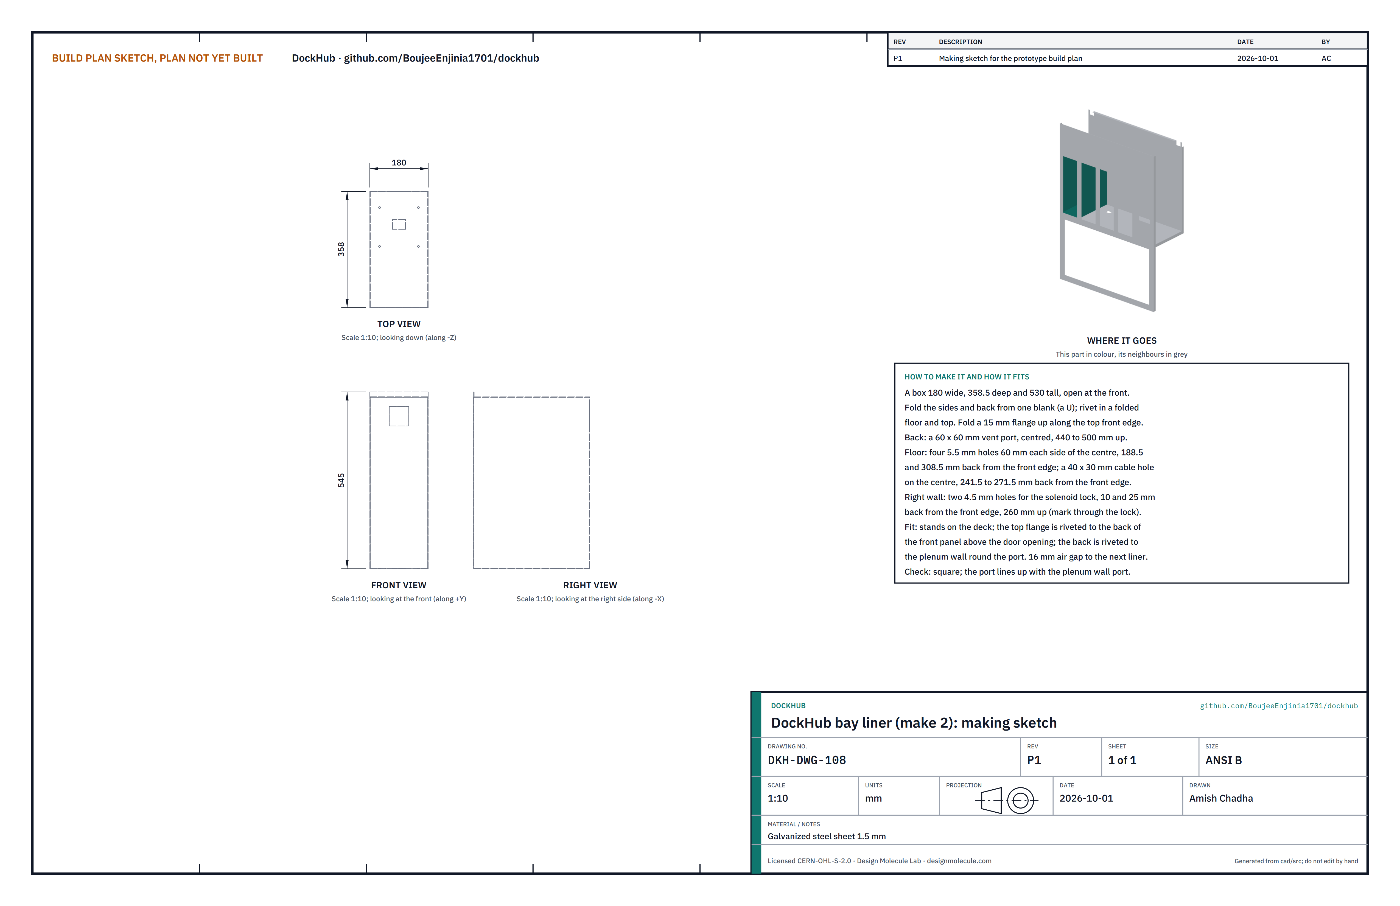
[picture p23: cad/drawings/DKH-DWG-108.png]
Figure 11. Making sketch of the bay liner


*Figure 11. Bay liner making sketch (DKH-DWG-108).*

**What it is and what it is made from.** The steel box each pack stands in, open at the front, which keeps a pack fault inside its own bay. Galvanized steel sheet 1.5 mm.

**How to make it.**

1. Fold the two sides and the back from one blank into a U, 180 mm wide, 358.5 mm deep and 530 mm tall.
2. Fold a floor tray and a top tray and rivet them in. Along the top front edge, fold a 15 mm flange upward.
3. In the back, cut a 60 x 60 mm vent port, centred, 440 to 500 mm up from the liner's bottom.
4. In the floor, drill four 5.5 mm holes and cut a 40 x 30 mm cable hole at the same places as the deck holes (section 3.6).
5. In the right wall, drill the two solenoid lock holes, marked through the lock, near the front edge at 235 to 285 mm up from the liner's bottom.

**How it fits the parts next to it.**

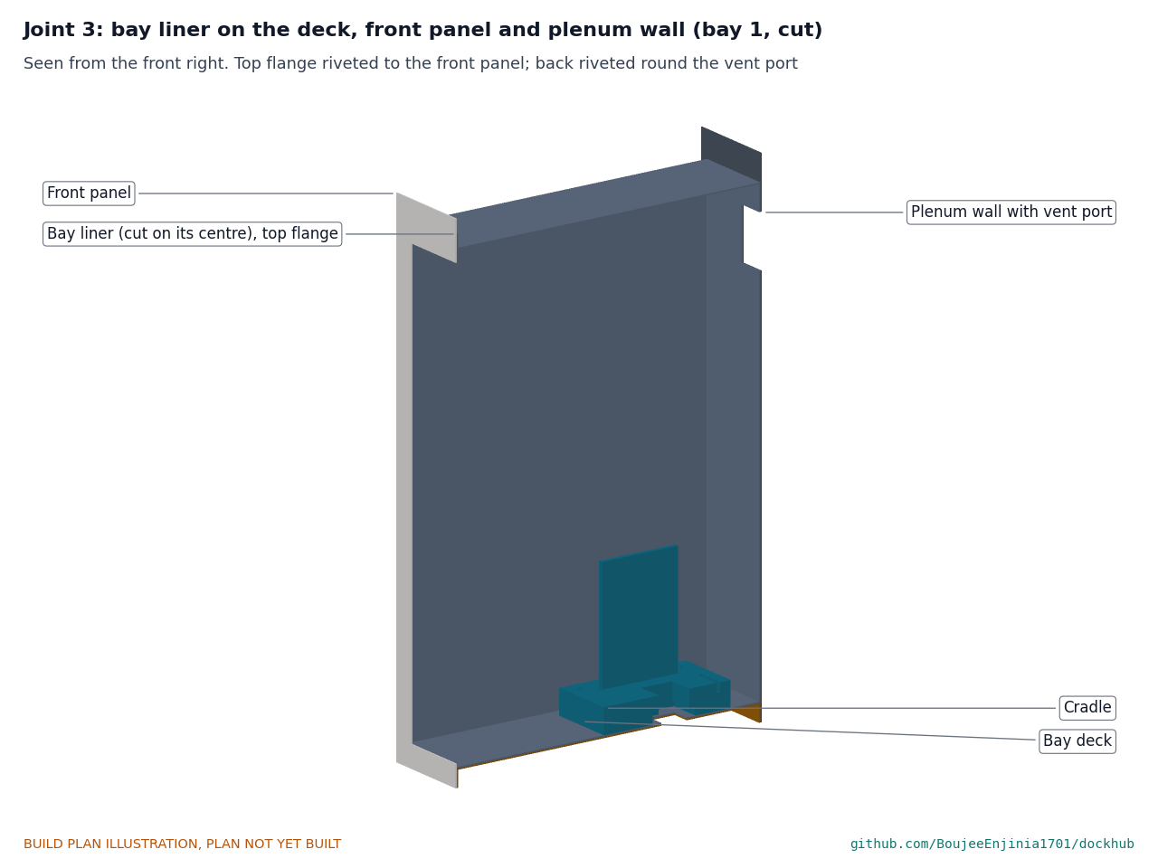
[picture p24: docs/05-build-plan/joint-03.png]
Figure 12. Joint 3: bay liner, deck, front panel and plenum wall


*Figure 12. Bay 1 cut on its centre: the liner stands on the deck, its top flange lies against the back of the front panel above the door opening, and its back lies against the plenum wall round the vent port.*

The liner stands on the deck, its back flat against the plenum wall and its open front against the back of the front panel. The top flange is riveted to the front panel above the door opening; the back is riveted to the plenum wall round the port, from inside the liner; the floor is held to the deck by the four cradle screws. There is a 16 mm air gap between neighbouring liners and 16.5 mm between bay 1's liner and the side panel.

**Check before moving on.** Square; the port lines up with the plenum wall port.

### 3.9 Cradles (print 2)

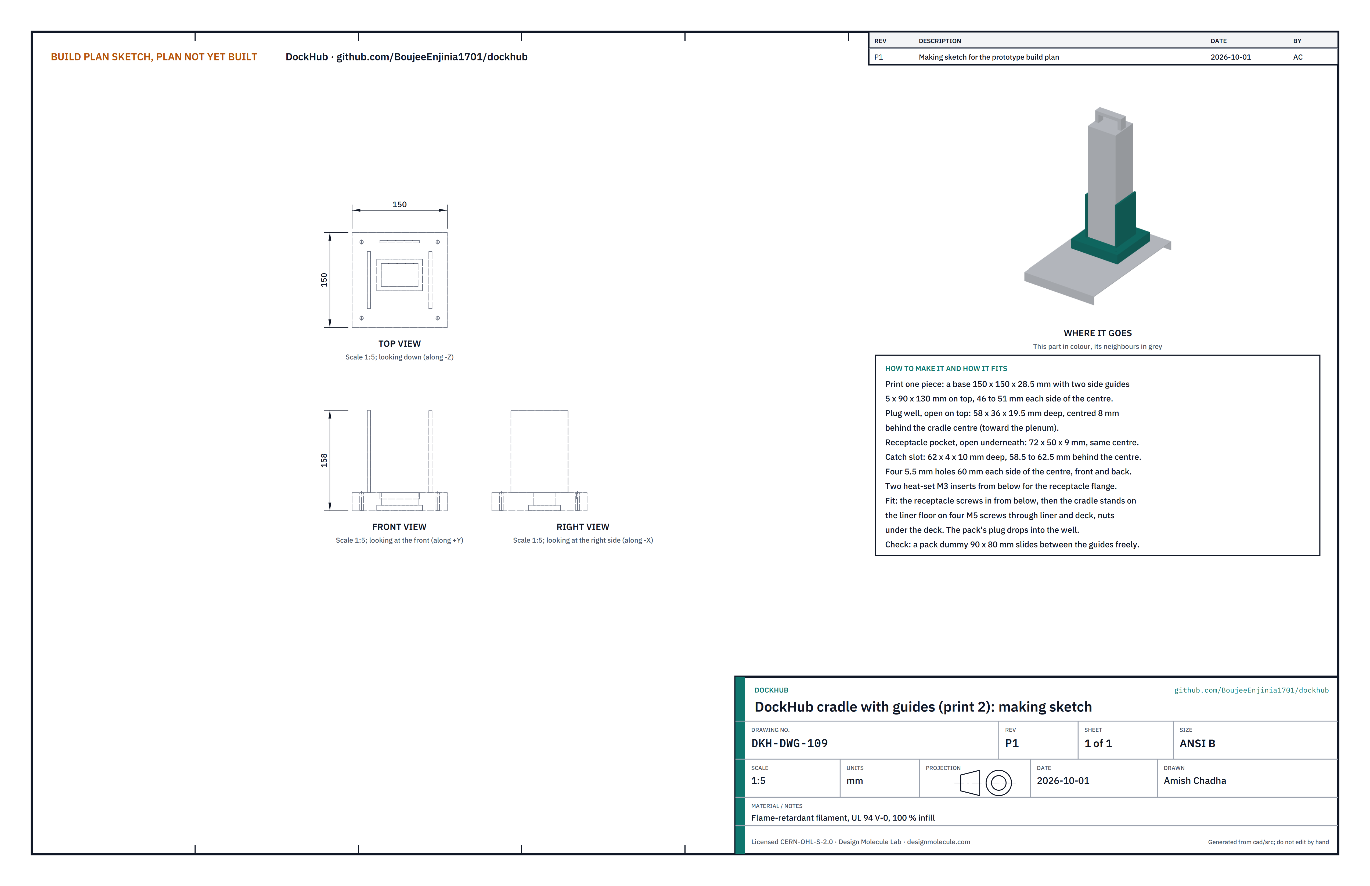
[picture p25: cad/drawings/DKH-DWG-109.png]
Figure 13. Making sketch of the cradle


*Figure 13. Cradle making sketch (DKH-DWG-109).*

**What it is and what it is made from.** The printed block each pack stands on, with the side guides that steer it onto the receptacle. A flame-retardant filament rated UL 94 V-0, printed at 100 % infill.

**How to make it.**

1. Print one piece: a base 150 x 150 x 28.5 mm with two side guides 5 mm thick, 90 mm long and 130 mm tall on top, their inner faces 46 mm each side of the centre (the pack is 90 mm wide).
2. The print includes: a plug well open on top, 58 x 36 mm and 19.5 mm deep, centred 8 mm behind the cradle centre; a receptacle pocket open underneath, 72 x 50 mm and 9 mm deep, on the same centre; a catch slot 62 x 4 mm and 10 mm deep, 58.5 to 62.5 mm behind the centre; and four 5.5 mm holes 60 mm each side of the centre, front and back.
3. Press two M3 heat-set inserts into the pocket roof for the receptacle flange.
4. Put the receptacle into its pocket from below and fix it with two M3 screws.

**How it fits the parts next to it.**

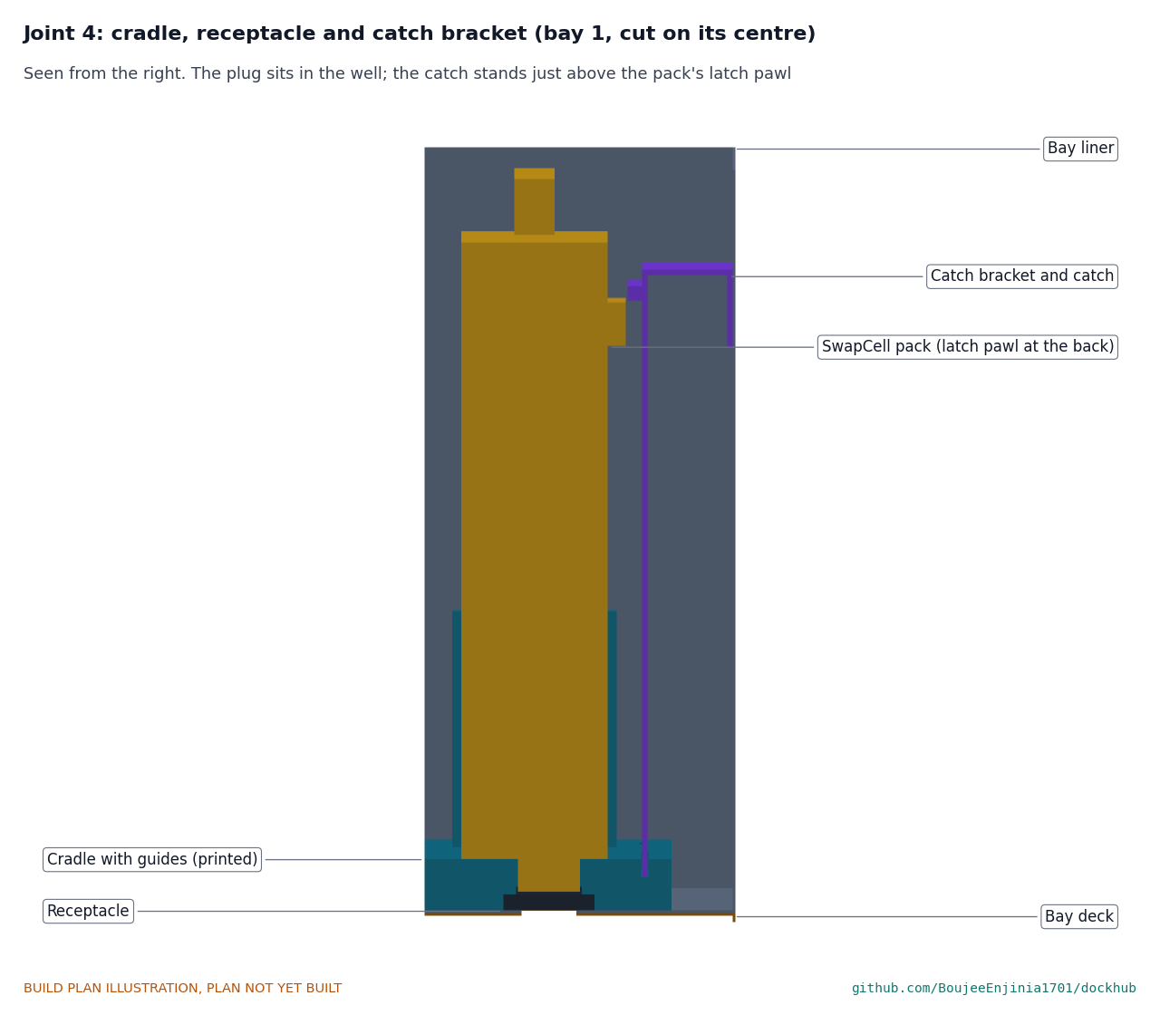
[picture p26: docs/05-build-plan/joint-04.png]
Figure 14. Joint 4: cradle, receptacle and catch bracket


*Figure 14. Bay 1 cut on its centre, with a pack in place: the plug sits in the well over the receptacle, and the catch stands just above the pack's latch pawl.*

The cradle stands on the liner floor on four M5 screws down through the liner floor and the deck, nuts under the deck. The receptacle's lead goes down through the cable holes to the technical compartment. The pack stands connector down between the guides with its plug in the well.

**Check before moving on.** A pack dummy 90 x 80 mm slides between the guides without binding.

### 3.10 Catch brackets (make 2)

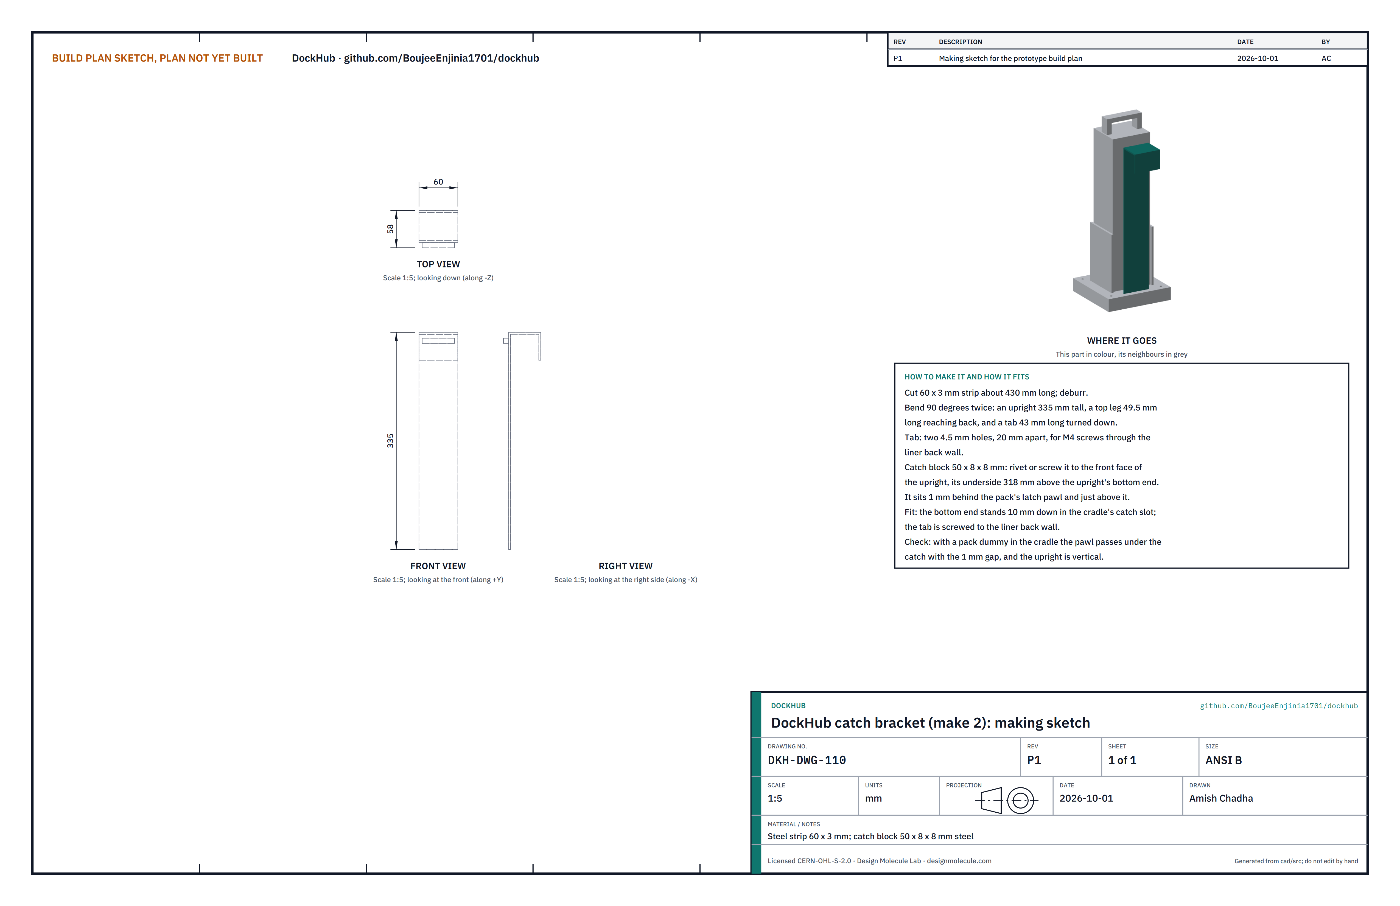
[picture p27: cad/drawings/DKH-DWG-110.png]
Figure 15. Making sketch of the catch bracket


*Figure 15. Catch bracket making sketch (DKH-DWG-110).*

**What it is and what it is made from.** The folded strip that holds the class D catch over the pack's latch pawl. Steel strip 60 x 3 mm, with a 50 x 8 x 8 mm steel catch block.

**How to make it.**

1. Cut 60 x 3 mm strip about 430 mm long and deburr it.
2. Bend it 90° twice: an upright 335 mm tall, a top leg 49.5 mm long reaching back, and a tab 43 mm long turned down.
3. Drill two 4.5 mm holes in the tab, 20 mm apart.
4. Rivet or screw the catch block to the front face of the upright, its underside 318 mm above the upright's bottom end.

**How it fits the parts next to it.** The upright's bottom end stands 10 mm down in the cradle's catch slot; the tab is screwed to the liner back wall with two M4 screws (Figure 14). The catch then sits 1 mm behind the pack's pawl and just above it, as SwapCell interface v0.3 requires.

**Check before moving on.** With a pack dummy in the cradle the pawl passes under the catch with the 1 mm gap; the upright is vertical.

### 3.11 Front panel

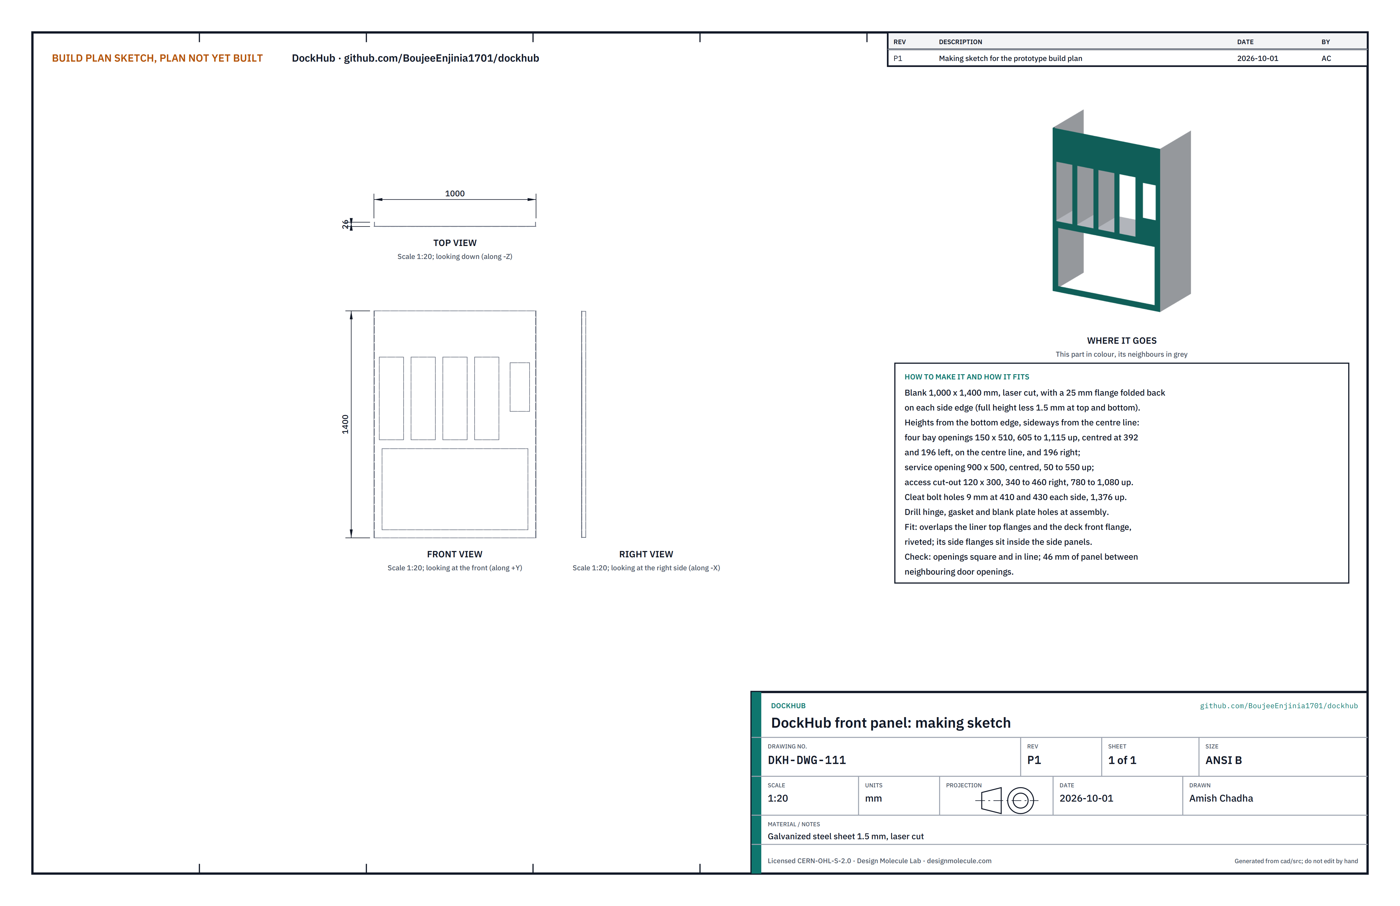
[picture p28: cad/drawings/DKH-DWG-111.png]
Figure 16. Making sketch of the front panel


*Figure 16. Front panel making sketch (DKH-DWG-111).*

**What it is and what it is made from.** The street face of the cabinet, with the door openings, the service opening and the access panel cut-out. Galvanized steel sheet 1.5 mm, laser cut by the sheet metal shop.

**How to make it.**

1. Cut a blank 1,000 x 1,400 mm with a 25 mm flange on each side edge, the flanges 1.5 mm short of the top and bottom edges. Heights below are from the panel's bottom edge.
2. Cut four bay openings 150 x 510 mm, 605 to 1,115 mm up, centred 392 and 196 mm left of the centre line, on it, and 196 mm right of it.
3. Cut the service opening 900 x 500 mm, centred, 50 to 550 mm up, and the access cut-out 120 x 300 mm, 340 to 460 mm right of centre, 780 to 1,080 mm up.
4. Drill the four roof cleat bolt holes, 9 mm, 410 and 430 mm each side of the centre, 1,376 mm up.
5. Fold the side flanges 90° back. Leave hinge, gasket and blank plate holes until the parts are fitted.

**How it fits the parts next to it.** Its side flanges sit inside the side panels and are riveted through them (Figure 7). Its back face lies on the deck's front flange and on each liner's top flange, all riveted from the front.

**Check before moving on.** Openings square and in line; 46 mm of panel between neighbouring door openings.

### 3.12 Roof beams with cleats (make 2)

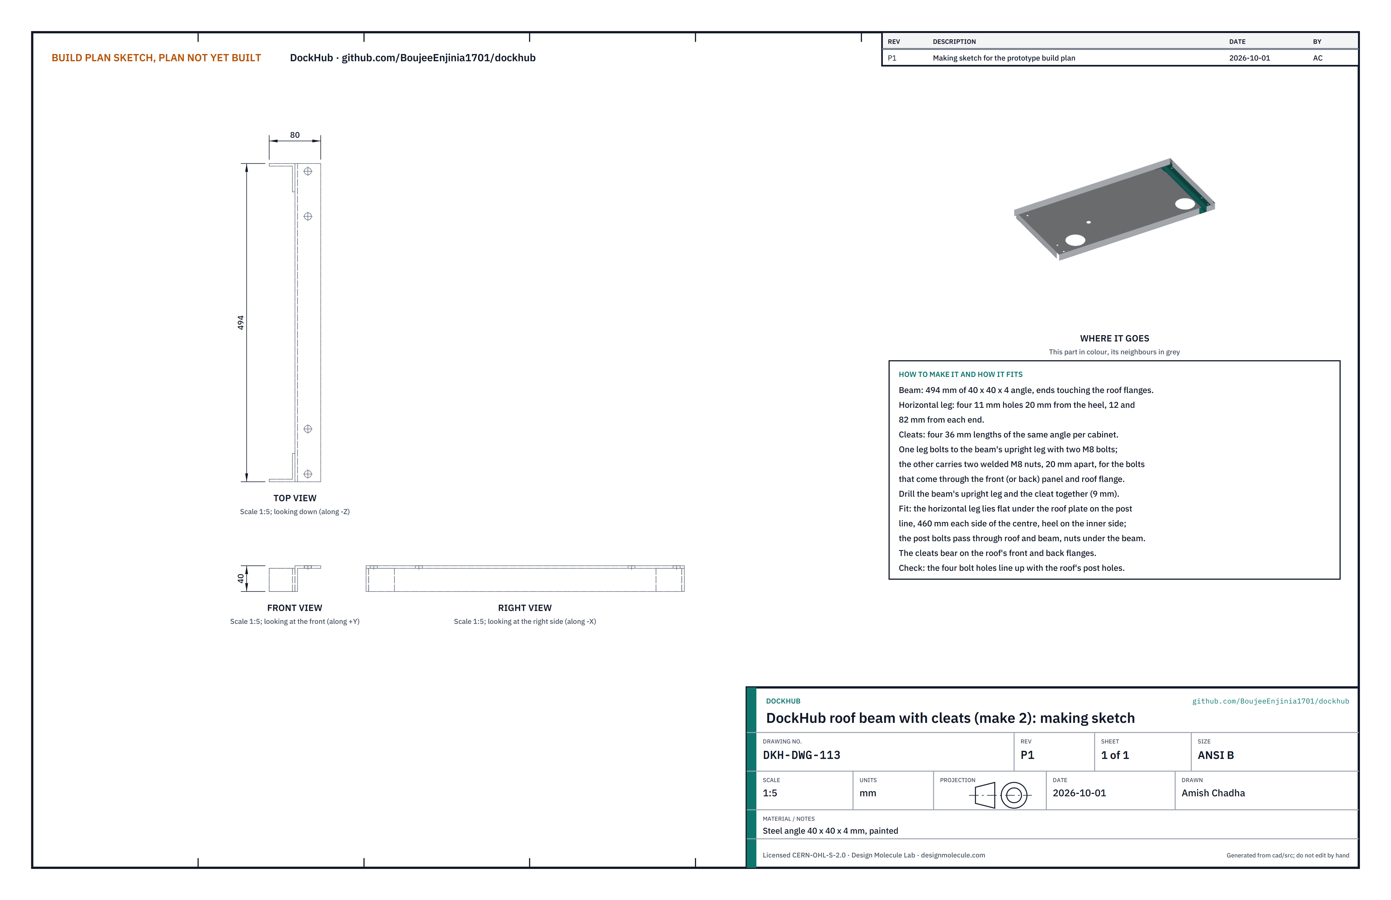
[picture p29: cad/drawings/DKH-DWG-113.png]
Figure 17. Making sketch of the roof beam


*Figure 17. Roof beam making sketch (DKH-DWG-113).*

**What it is and what it is made from.** The two steel angles under the roof that the canopy posts bolt down into, and that carry the canopy's lift into the front and back panels. Steel angle 40 x 40 x 4 mm, painted.

**How to make it.**

1. Cut two beams 494 mm long. In the horizontal leg of each, drill four 11 mm holes on a line 20 mm from the heel, 12 and 82 mm from each end.
2. Cut four cleats 36 mm long from the same angle. Weld two M8 nuts, 20 mm apart, to the inside face of one leg of each cleat, over 9 mm holes.
3. Clamp a cleat's other leg to each end of a beam's upright leg and drill both 9 mm for two M8 bolts. Bolt them together.

**How it fits the parts next to it.**

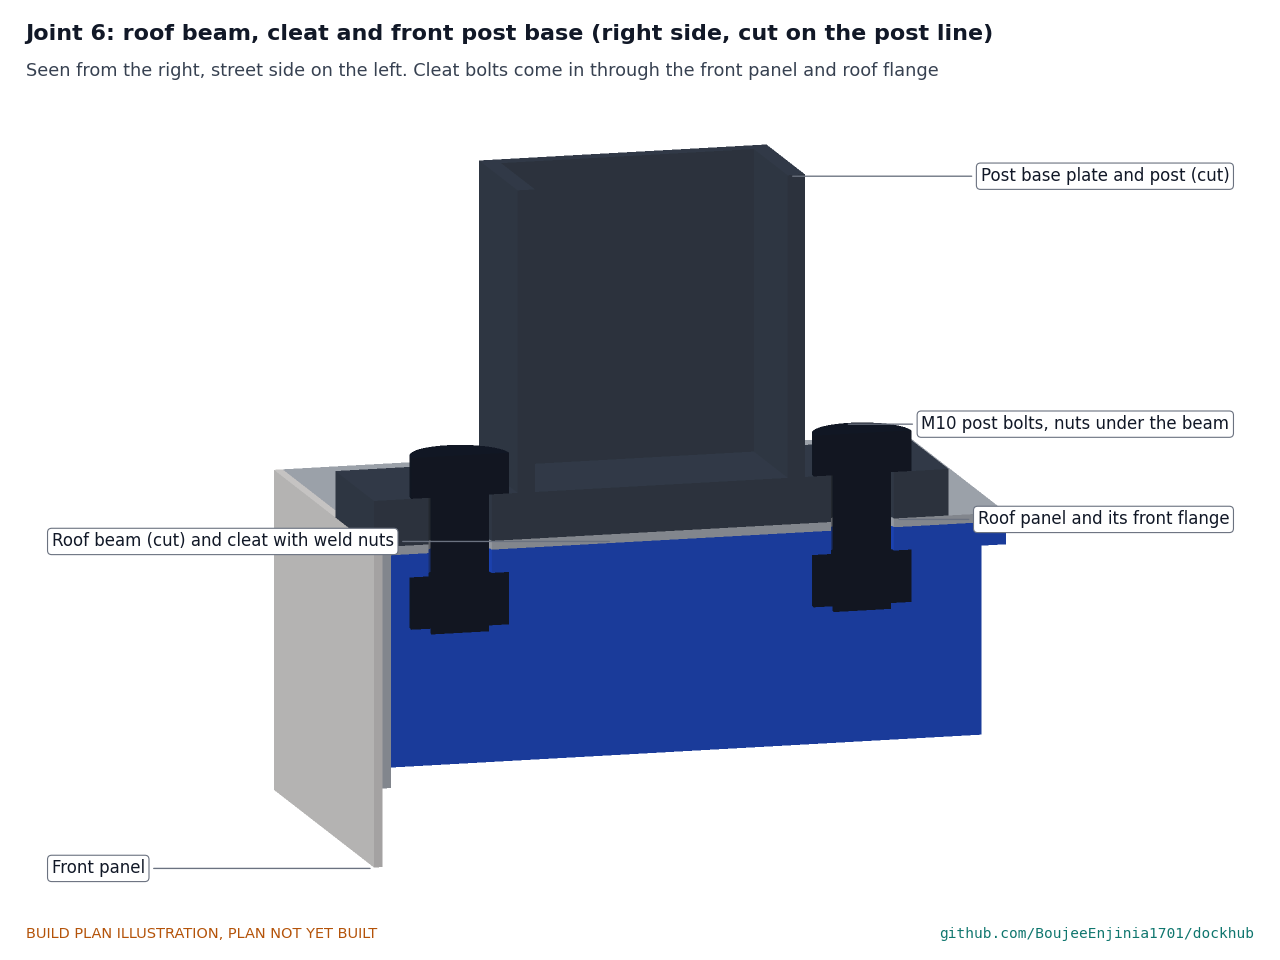
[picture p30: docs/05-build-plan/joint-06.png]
Figure 18. Joint 6: roof beam, cleat and front post base


*Figure 18. Cut on the right post line: the beam's horizontal leg lies under the roof, the post's base plate on top, two M10 bolts through all three; the cleat at the beam end lies against the roof's front flange.*

Each beam's horizontal leg lies flat under the roof plate on a post line, 460 mm each side of the centre, with the upright leg on the inner side, and its ends touch the roof's front and back flanges. The cleats' nut legs lie against the roof flanges; M8 bolts come in from outside through the front (or back) panel and the roof flange into the welded nuts, so nothing has to be reached inside. The post bolts pass through base plate, roof and beam.

**Check before moving on.** The four holes in each beam line up with the post holes in the roof.

### 3.13 Roof panel

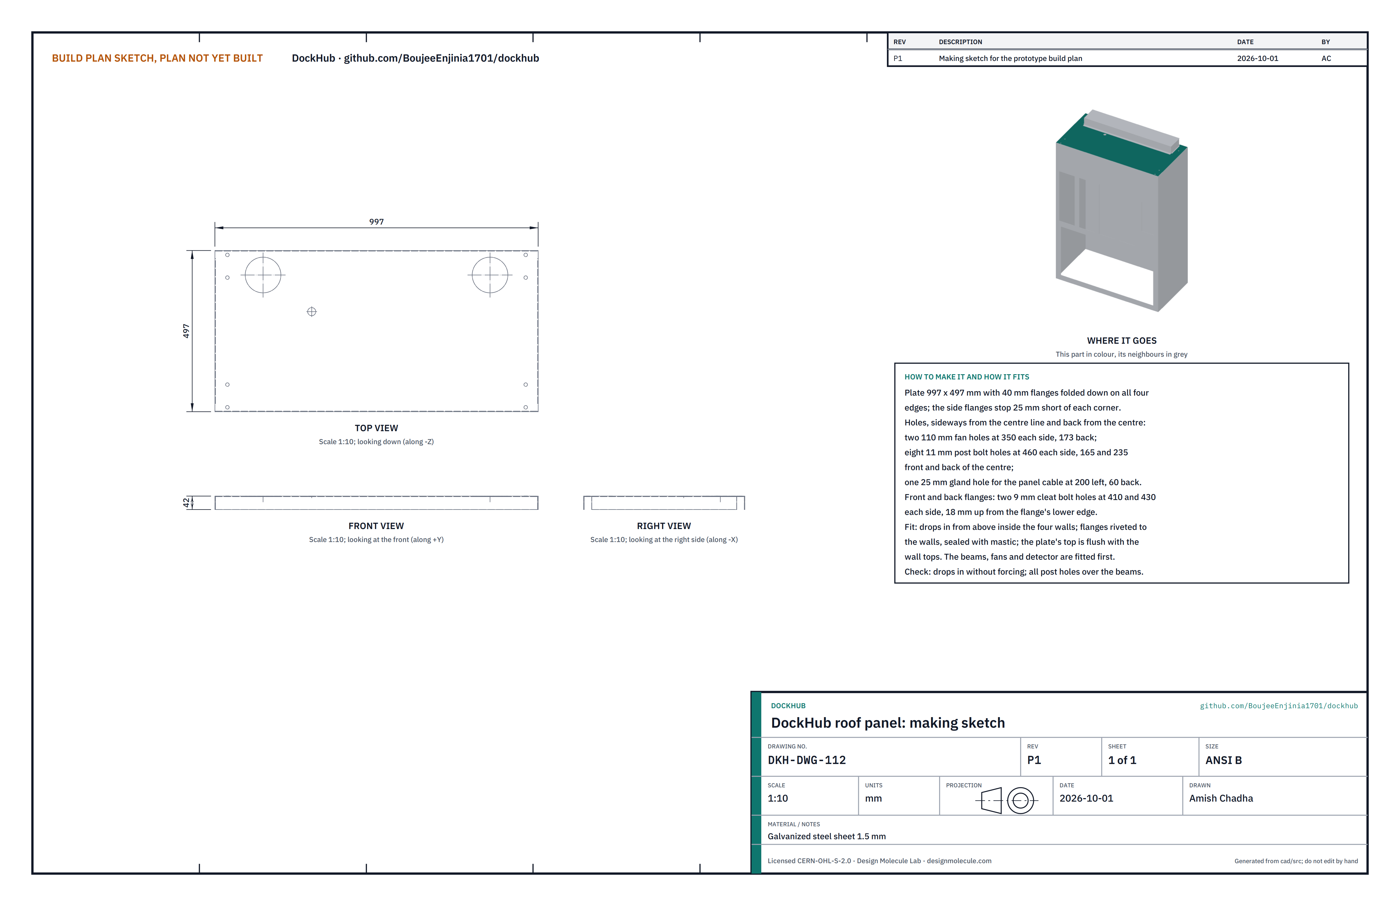
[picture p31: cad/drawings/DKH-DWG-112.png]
Figure 19. Making sketch of the roof panel


*Figure 19. Roof panel making sketch (DKH-DWG-112).*

**What it is and what it is made from.** The roof of the cabinet; the beams, fans and detector are fitted under it before it goes on. Galvanized steel sheet 1.5 mm.

**How to make it.**

1. Cut a plate 997 x 497 mm with a 40 mm flange on every edge, the side flanges 25 mm short at each end.
2. Fold all four flanges down 90°.
3. Cut two 110 mm fan holes, 350 mm each side of the centre and 173 mm behind it, and one 25 mm hole for the panel cable gland, 200 mm left of centre and 60 mm behind it.
4. Drill eight 11 mm post bolt holes, 460 mm each side of the centre, 165 and 235 mm in front of and behind the centre.
5. In the front and back flanges, drill two 9 mm cleat bolt holes 410 and 430 mm each side of the centre, 18 mm up from the flange's lower edge.

**How it fits the parts next to it.** It drops in from above inside the four walls with its top flush with the wall tops; its flanges are riveted to the walls and sealed with mastic. The fans hang under it on spacers and blow up through the holes into the vent hood:

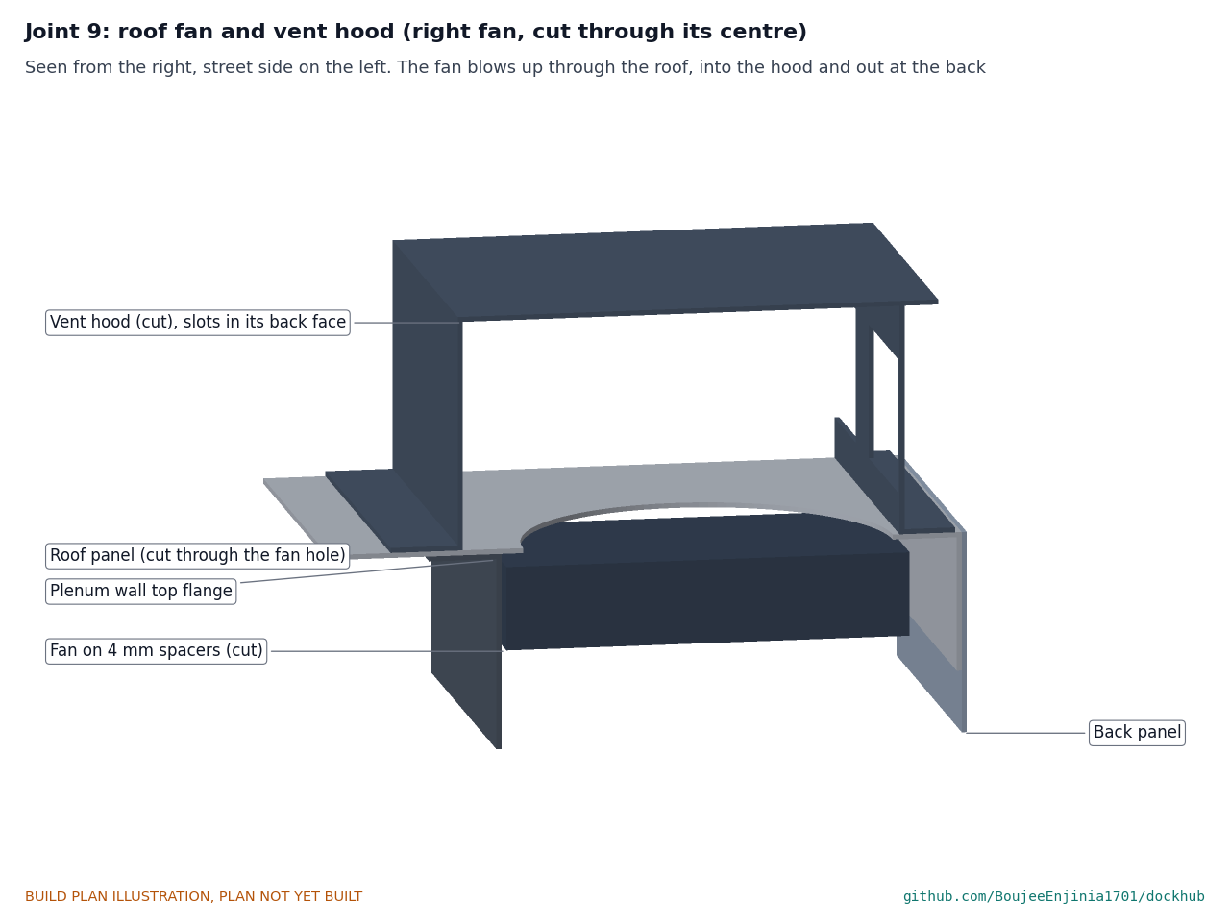
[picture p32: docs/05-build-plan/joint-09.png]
Figure 20. Joint 9: roof fan and vent hood


*Figure 20. The right fan cut through its centre: the fan on 4 mm spacers under the roof, the hole above it, and the hood over the hole with its slots at the back.*

**Check before moving on.** It drops in without forcing, with all eight post holes over the beams.

### 3.14 Vent hood

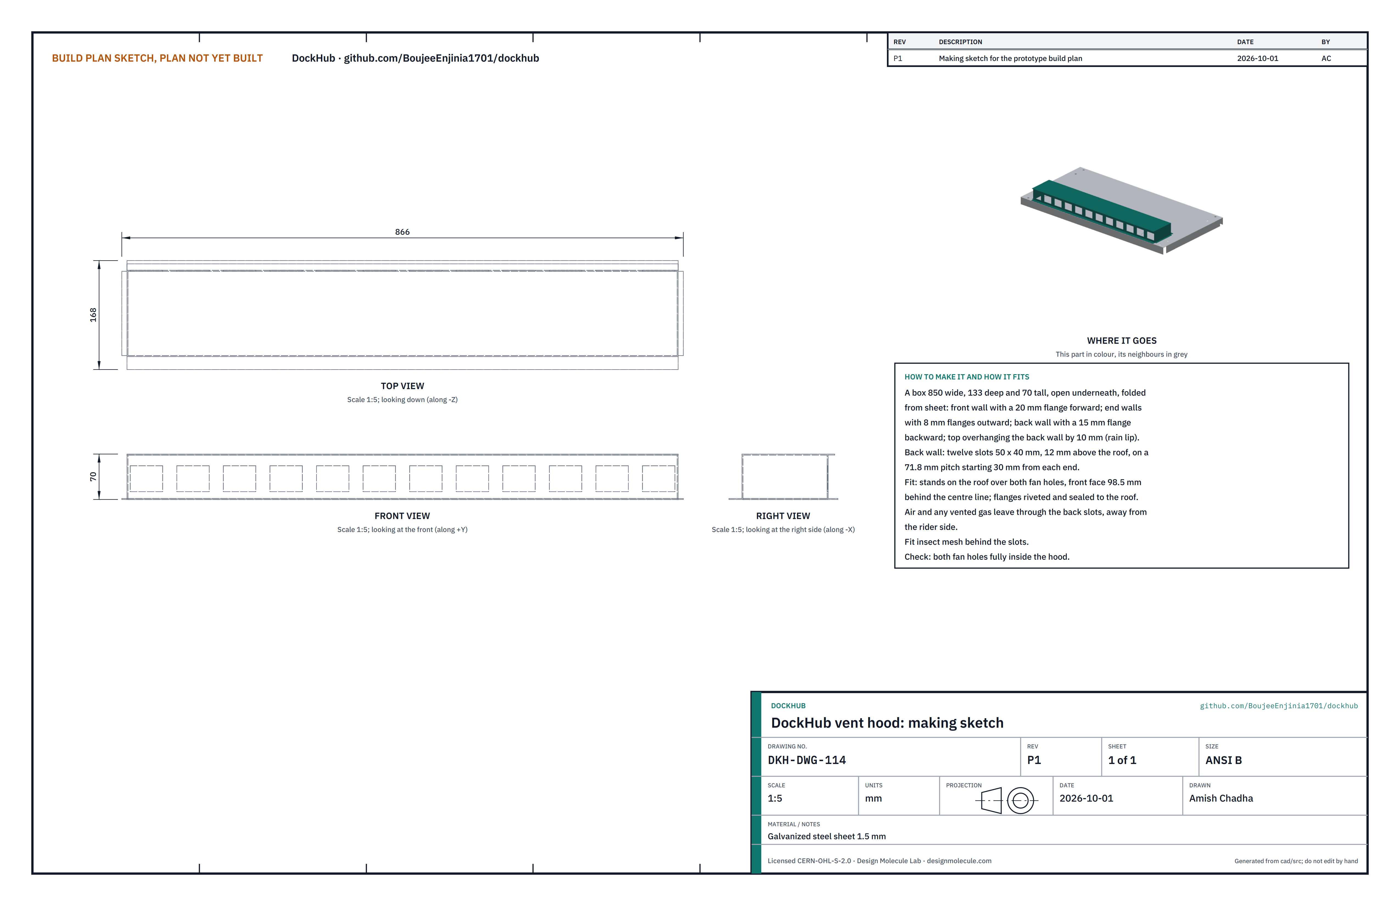
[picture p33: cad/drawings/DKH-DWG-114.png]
Figure 21. Making sketch of the vent hood


*Figure 21. Vent hood making sketch (DKH-DWG-114).*

**What it is and what it is made from.** The folded cover over the two fan holes that turns the outflow to the back of the cabinet and keeps rain out. Galvanized steel sheet 1.5 mm.

**How to make it.**

1. Fold a box 850 mm wide, 133 mm deep and 70 mm tall, open underneath: a front wall with a 20 mm flange forward, end walls with 8 mm flanges outward, a back wall with a 15 mm flange backward, and a top that overhangs the back wall by 10 mm as a rain lip.
2. In the back wall, cut twelve slots 50 x 40 mm, 12 mm above the bottom edge, on a 71.8 mm pitch starting 30 mm from each end. Fit insect mesh behind them.

**How it fits the parts next to it.** It stands on the roof over both fan holes, its front face 98.5 mm behind the centre line; its flanges are riveted and sealed to the roof (Figure 20). Air and any vented gas leave through the back slots, away from the rider side.

**Check before moving on.** Both fan holes lie fully inside the hood.

### 3.15 Bay doors and blank plates (make 2 of each)

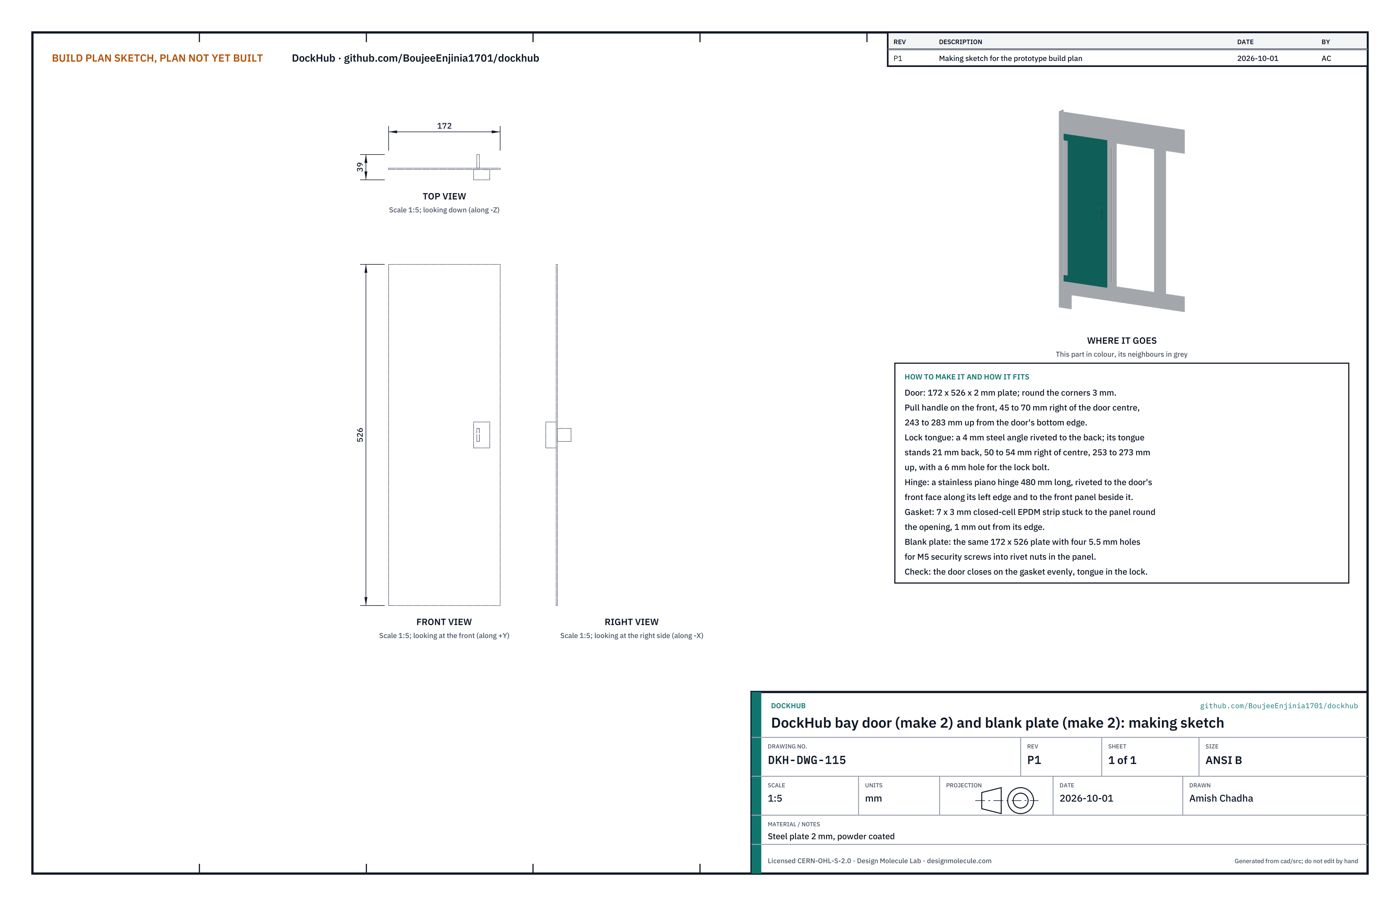
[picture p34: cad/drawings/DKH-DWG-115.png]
Figure 22. Making sketch of the bay door and blank plate


*Figure 22. Bay door and blank plate making sketch (DKH-DWG-115).*

**What it is and what it is made from.** The locking door over each fitted bay, and the plate that closes each unfitted bay. Steel plate 2 mm, powder coated.

**How to make it.**

1. Cut four plates 172 x 526 mm and round the corners 3 mm. Two become doors, two blank plates.
2. Doors: fit the pull handle on the front, 45 to 70 mm right of the door centre and 243 to 283 mm up from its bottom edge. Rivet a small 4 mm steel angle to the back as the lock tongue: the tongue stands 21 mm back from the door, 50 to 54 mm right of centre, 253 to 273 mm up, with a 6 mm hole for the lock bolt.
3. Blank plates: drill four 5.5 mm holes, 10 mm in from the corners, for M5 security screws.

**How it fits the parts next to it.**

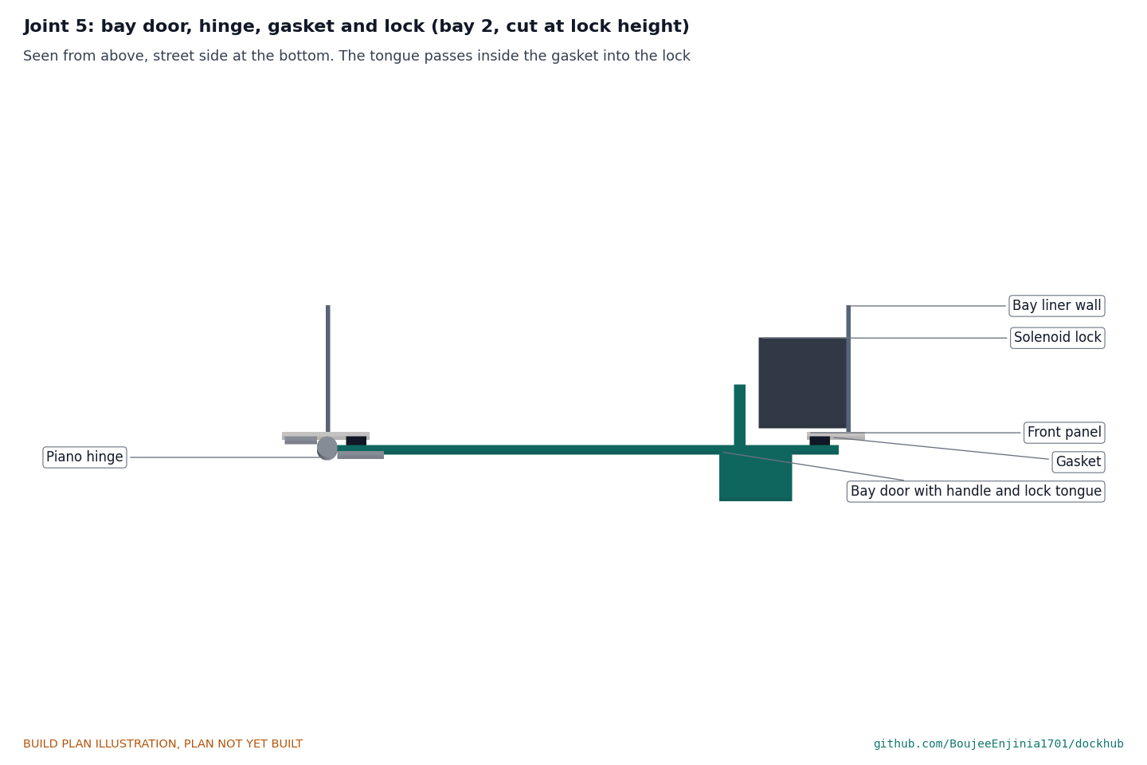
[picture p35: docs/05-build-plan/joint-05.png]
Figure 23. Joint 5: bay door, hinge, gasket and lock


*Figure 23. Bay 2 cut at lock height and seen from above: the hinge on the left, the gasket between door and panel, and the tongue entering the lock on the liner wall.*

Each door covers its 150 mm opening with 11 mm to spare at each side and 8 mm at top and bottom, so it closes on a 7 x 3 mm EPDM gasket stuck to the panel 1 mm out from the opening's edge. A stainless piano hinge 480 mm long is riveted along the door's left edge and to the panel beside it, its knuckle in the 24 mm gap between doors. The tongue passes inside the gasket into the solenoid lock. Blank plates go on four M5 security screws into rivet nuts in the panel.

**Check before moving on.** The door closes onto the gasket evenly and the tongue enters the lock without rubbing.

### 3.16 Service door

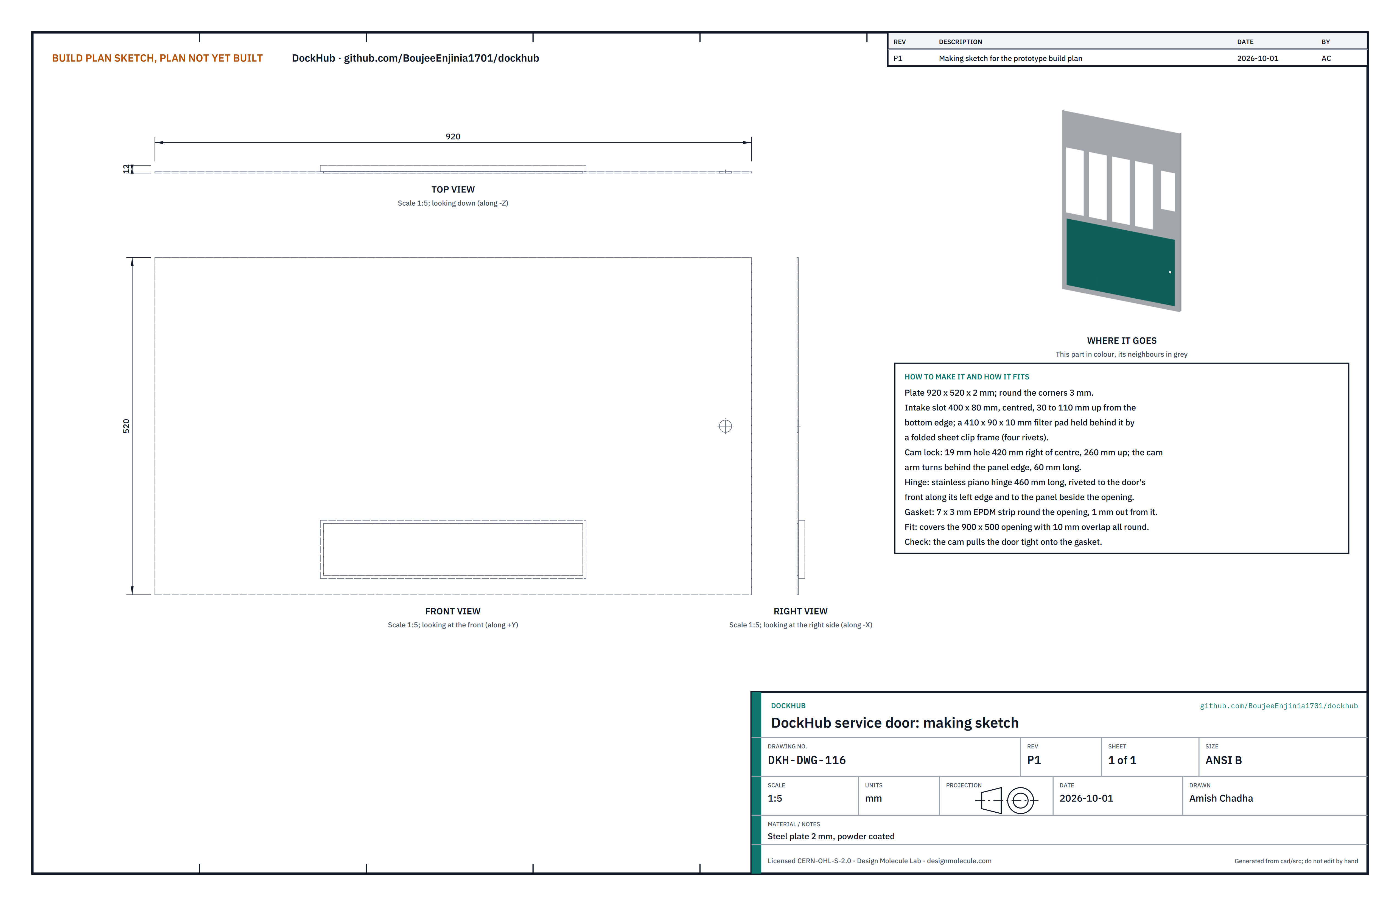
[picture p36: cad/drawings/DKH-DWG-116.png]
Figure 24. Making sketch of the service door


*Figure 24. Service door making sketch (DKH-DWG-116).*

**What it is and what it is made from.** The locking door over the technical compartment, with the filtered air intake. Steel plate 2 mm, powder coated.

**How to make it.**

1. Cut a plate 920 x 520 mm and round the corners 3 mm.
2. Cut the intake slot 400 x 80 mm, centred, 30 to 110 mm up from the bottom edge, and fold a sheet clip frame that holds a 410 x 90 x 10 mm filter pad behind it (four rivets).
3. Cut a 19 mm hole for the cam lock 420 mm right of centre and 260 mm up from the bottom edge.

**How it fits the parts next to it.**

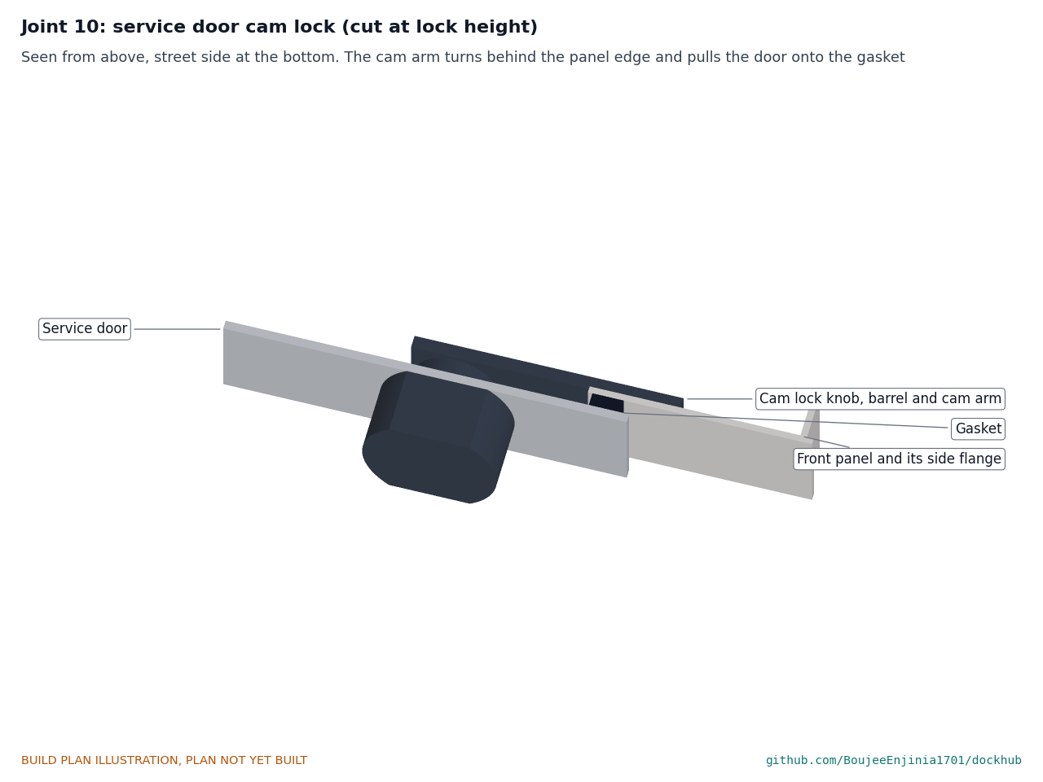
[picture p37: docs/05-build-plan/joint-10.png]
Figure 25. Joint 10: service door cam lock


*Figure 25. Cut at lock height and seen from above: the cam arm turns behind the panel edge and pulls the door onto the gasket.*

The door covers the 900 x 500 mm opening with 10 mm to spare all round and closes on a 7 x 3 mm EPDM gasket. A stainless piano hinge 460 mm long runs along its left edge. The cam lock's arm, 60 mm long, turns behind the panel beside the opening.

**Check before moving on.** The cam pulls the door tight onto the gasket.

### 3.17 Canopy posts (make 4)

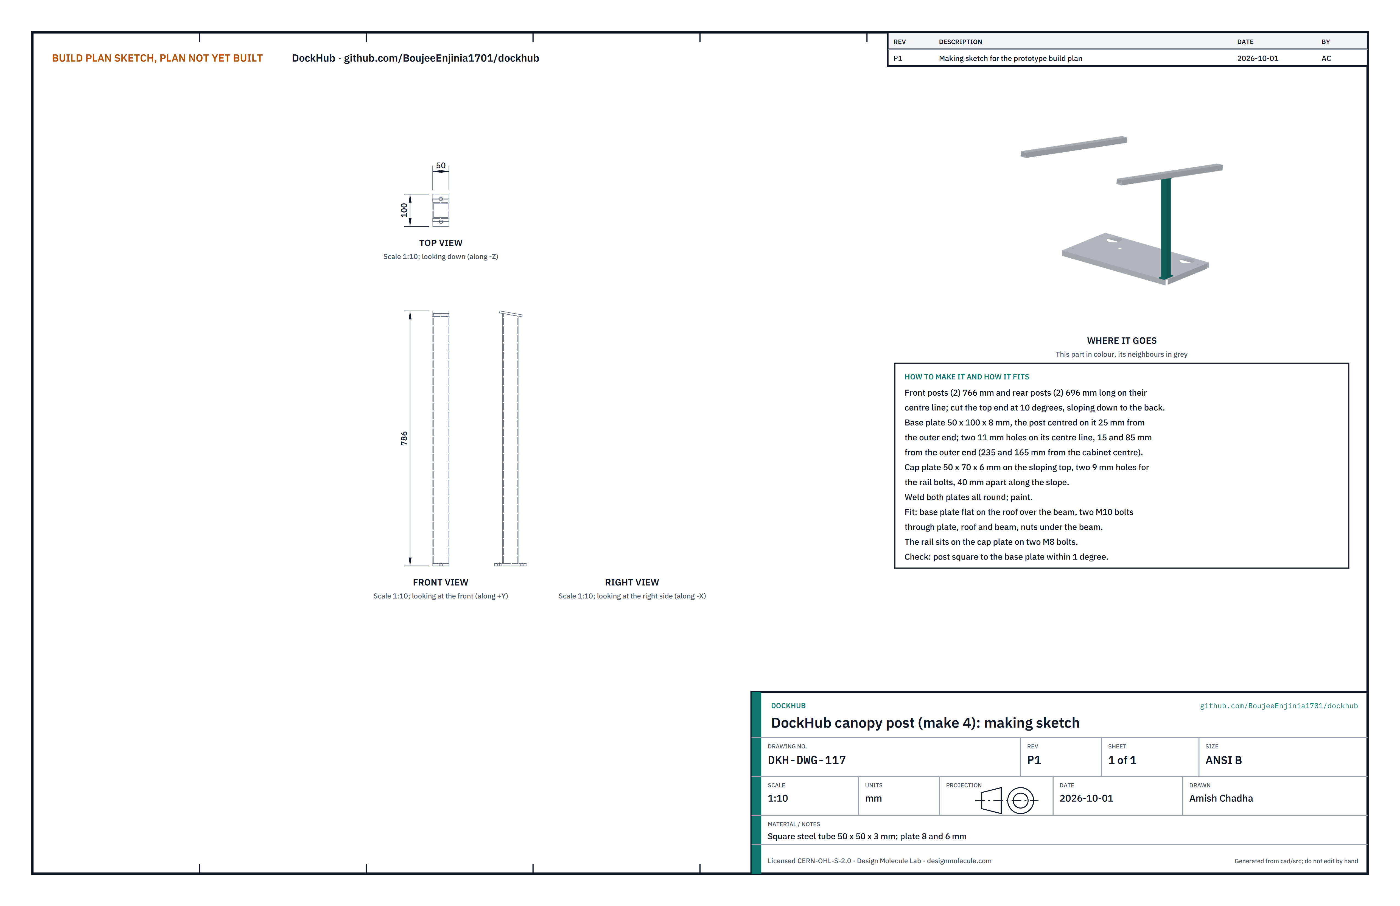
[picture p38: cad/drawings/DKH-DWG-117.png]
Figure 26. Making sketch of the canopy post


*Figure 26. Canopy post making sketch (DKH-DWG-117).*

**What it is and what it is made from.** The four legs of the canopy. Square steel tube 50 x 50 x 3 mm, with base plates 50 x 100 x 8 mm and cap plates 50 x 70 x 6 mm, painted.

**How to make it.**

1. Cut two front posts 766 mm long and two rear posts 696 mm long, measured on the tube's centre line, the top end cut at 10° so it slopes down toward the back.
2. Drill each base plate with two 11 mm holes on its centre line, 15 and 85 mm from its outer end. Weld the post to it, centred, with 25 mm of plate each side of the tube.
3. Drill each cap plate with two 9 mm holes 40 mm apart along the slope, and weld it on the sloping top.
4. Paint.

**How it fits the parts next to it.** Each base plate lies flat on the roof over a beam, its outer end flush with the front (or back) edge of the roof, on two M10 bolts through plate, roof and beam with sealing washers (Figure 18). The rail sits on the cap plate on two M8 bolts:

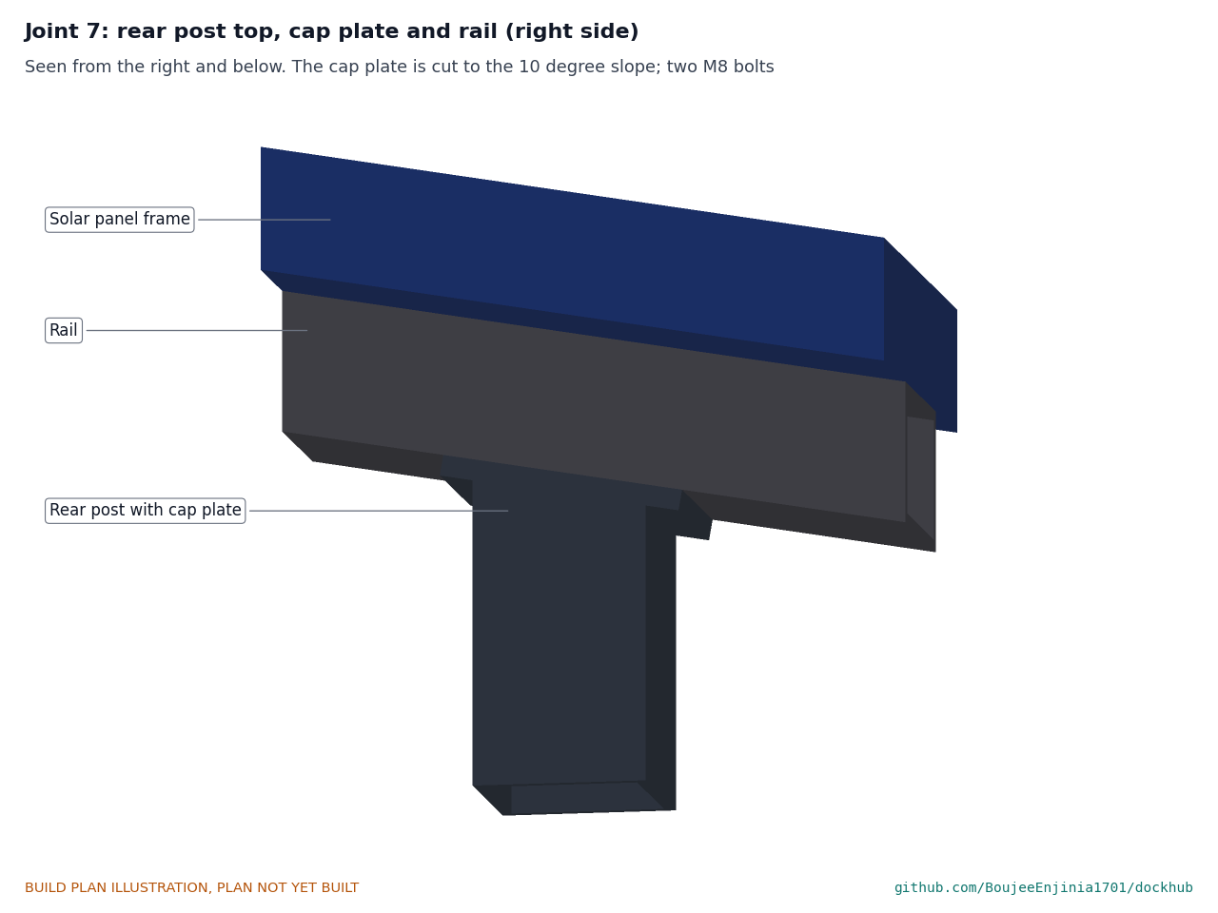
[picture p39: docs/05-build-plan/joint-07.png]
Figure 27. Joint 7: rear post top, cap plate and rail


*Figure 27. The right rear post: the cap plate is cut to the 10° slope and the rail sits flat on it.*

**Check before moving on.** Each post is square to its base plate within 1°.

### 3.18 Canopy rails (make 2)

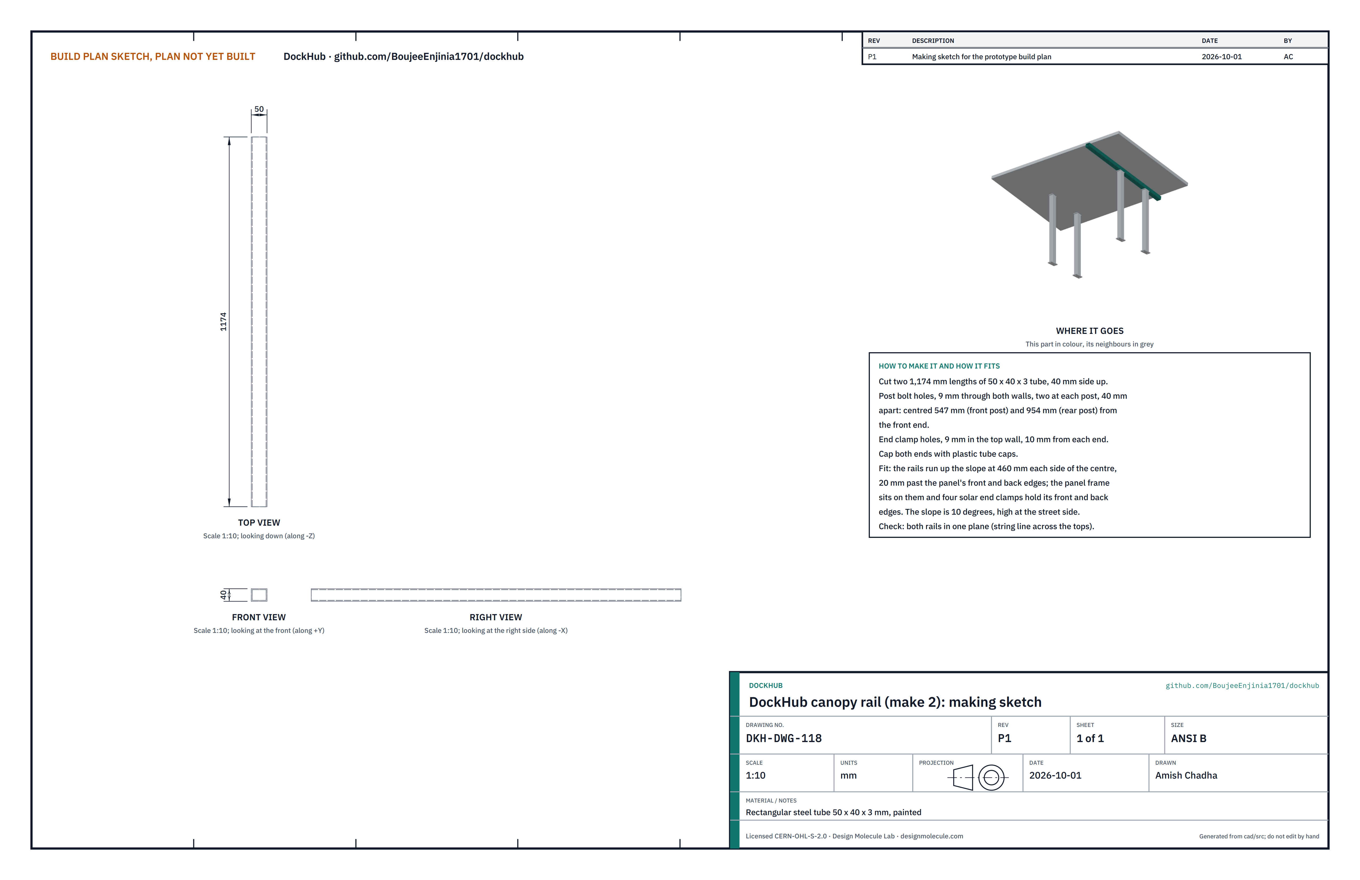
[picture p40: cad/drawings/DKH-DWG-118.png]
Figure 28. Making sketch of the canopy rail


*Figure 28. Canopy rail making sketch (DKH-DWG-118), drawn laid flat.*

**What it is and what it is made from.** The two rails the solar panel sits on. Rectangular steel tube 50 x 40 x 3 mm, painted.

**How to make it.**

1. Cut two lengths of 1,174 mm.
2. Drill the post bolt holes, 9 mm through both walls, two at each post, 40 mm apart, centred 547 mm (front post) and 954 mm (rear post) from the front end.
3. Drill a 9 mm end clamp hole in the top wall 10 mm from each end. Cap both ends.

**How it fits the parts next to it.** The rails run up the slope at 460 mm each side of the centre, high at the street side, and run 20 mm past the panel's front and back edges. The panel frame sits on them, and an end clamp at each end of each rail grips the frame's edge:

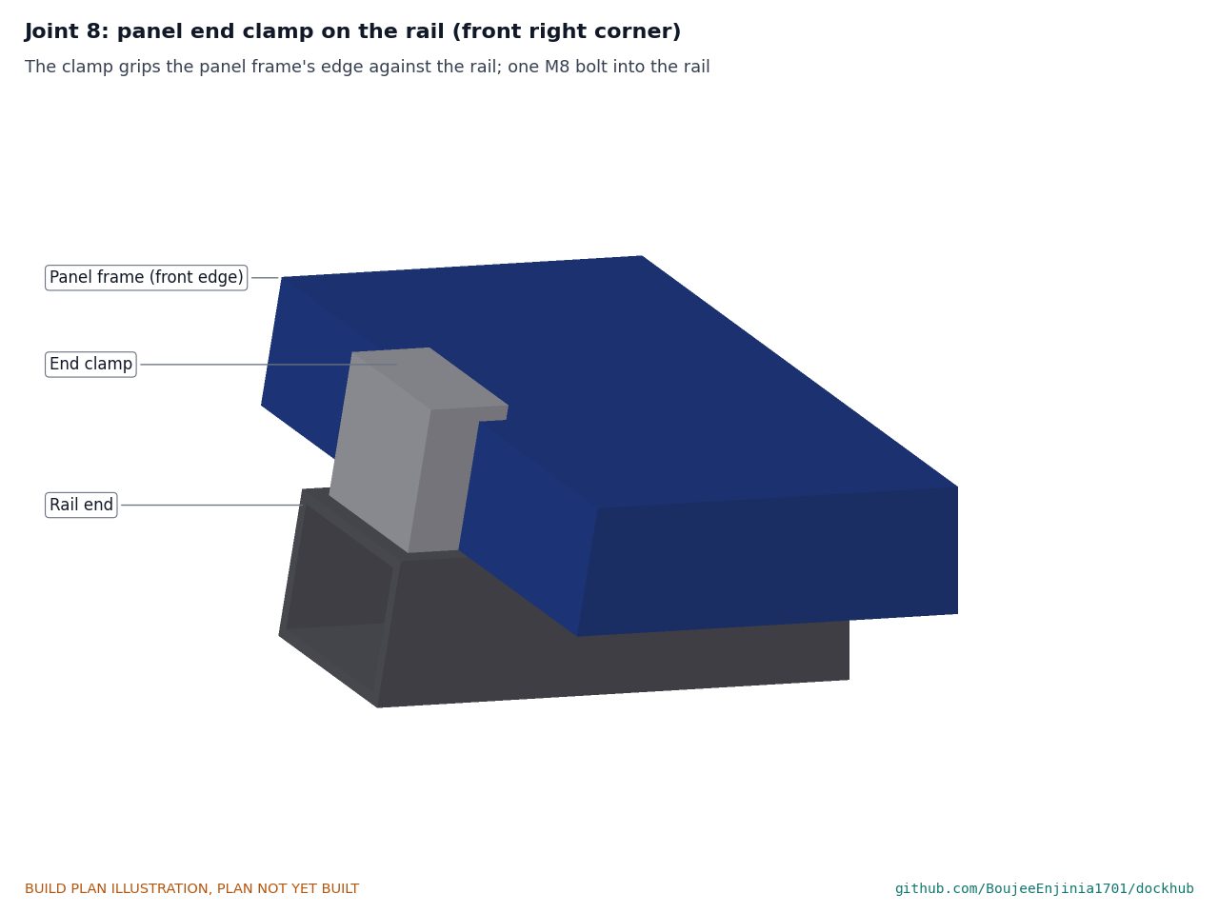
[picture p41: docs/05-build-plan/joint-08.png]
Figure 29. Joint 8: panel end clamp on the rail


*Figure 29. The front right end clamp holding the panel frame's edge onto the rail.*

**Check before moving on.** Both rails lie in one plane: a string line across their tops touches all four ends.

### 3.19 Bought components

Buy to specification, not brand. Line numbers are those of the bill of materials.

- **Chargers (line 5).** Certified lithium-ion chargers, 54.6 V, 5 A, CC-CV, 100 to 240 V input, power factor 0.9 or better, with screw-down feet.
- **Dock controller (line 6).** ESP32 with four CAN channels, contactors rated 60 V DC 10 A, current sensors, LTE-M modem and SD card, in a DIN box no larger than 220 x 100 x 190 mm.
- **Access panel (line 7).** Vandal-resistant NFC reader, sunlight-readable display, bay status lights and buzzer on a steel bezel 180 x 360 mm, fixed with security screws.
- **Grid input and protection (line 8).** DIN enclosure no larger than 220 x 92 x 200 mm with a 30 mA RCBO, a breaker per charger, surge protection, lockable isolator and gland. Installed and connected by a qualified electrician.
- **Fire detection and suppression (line 9).** Heat and smoke detector, and a condensed-aerosol unit about 76 mm across and 420 mm long with its maker's two straps.
- **Fans (line 10).** Two 120 x 120 x 25 mm fans, IP55, with corner holes on a 105 mm square; insect mesh; filter pad.
- **Receptacles (line 3).** SwapCell interface v0.3 blind-mate receptacle with its 10 kΩ INTERLOCK coding resistor and NTC, with a flange that fits the 72 x 50 mm pocket.
- **Solenoid locks (line 2).** 12 V fail-secure cabinet locks with a door switch, about 30 x 30 x 50 mm, whose bolt reaches the door tongue.
- **Solar panel (line 11).** 400 W monocrystalline, about 1,722 x 1,134 x 35 mm in an aluminium frame suited to standard end clamps, about 21 kg.
- **MPPT controller (line 13).** PV input up to 100 V, programmable lithium profile at 54.6 V, output limited to 5 A, no larger than 150 x 70 x 180 mm.
- **Anchors (line 17).** Four M12 x 160 mm stainless steel wedge anchors with a published approval for cracked concrete, each with a washer and a tamper-resistant nut; the approval data must give a design tension resistance of at least 3.8 kN at 100 mm embedment in C25/30 concrete. They are fitted at the site (section 9).
- **Hardware (lines 12 and 16).** Four solar end clamps for a 35 mm frame; eight M10 x 30 floor bolts and eight M10 x 40 post bolts with nyloc nuts and sealing washers; M8 cleat and rail bolts; M5 and M4 screws; 4 mm blind rivets; rivet nuts; stainless piano hinges (two 480 mm, one 460 mm); EPDM gasket strip 7 x 3 mm; fire-rated sealant and roof mastic; cable glands; the DC fuse per bay.

## 4. Putting it together

In each picture the parts already fitted are grey and the part being fitted is in colour, with an arrow showing the way it goes in. Two people are needed from step 13 on.

### Step 1: floor pan onto the plinth

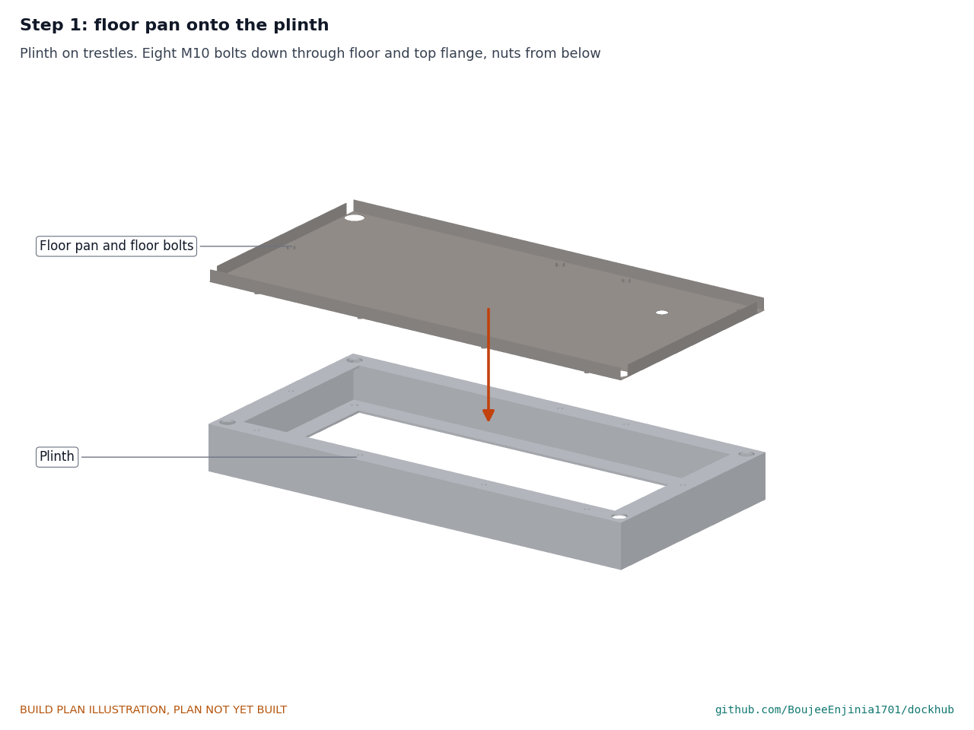
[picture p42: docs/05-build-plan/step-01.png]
Step 1


Stand the plinth on two timber bearers under its ends, about 150 mm high, so a hand reaches under the top flange. Lay the floor pan on it, bolt holes lined up, and fit eight M10 bolts down through floor and flange, nuts from below, tight.

### Step 2: back panel

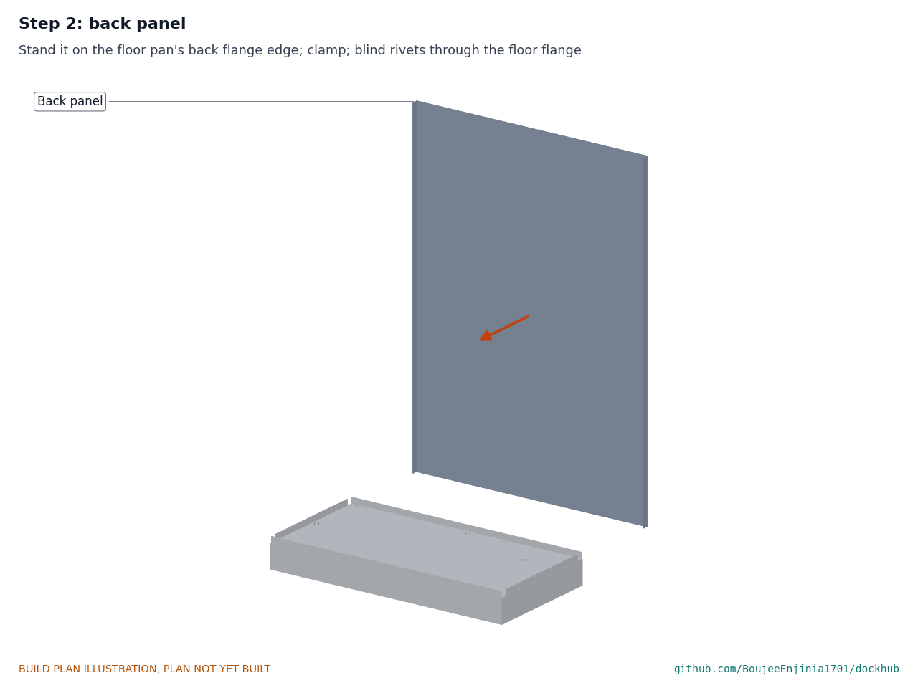
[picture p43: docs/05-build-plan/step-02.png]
Step 2


Stand the back panel on the floor pan's back edge, outside the floor flange, and clamp it upright. Drill and rivet through the floor flange.

### Step 3: side panels

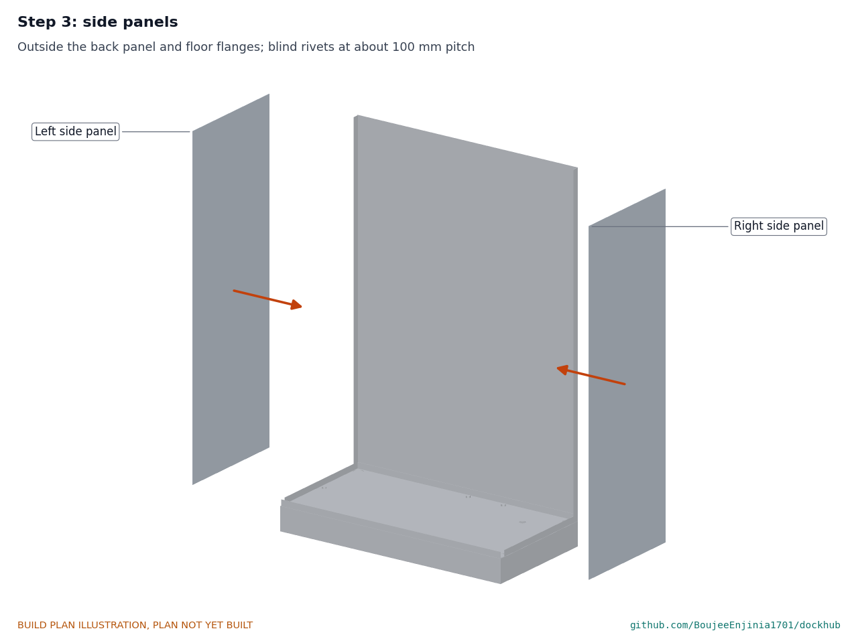
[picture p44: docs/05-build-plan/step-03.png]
Step 3


Stand each side panel on the floor pan's edge, outside the back panel's flange and the floor flange. Check the cabinet is square, then drill and rivet both joints.

### Step 4: controller, MPPT and grid boxes onto the back panel

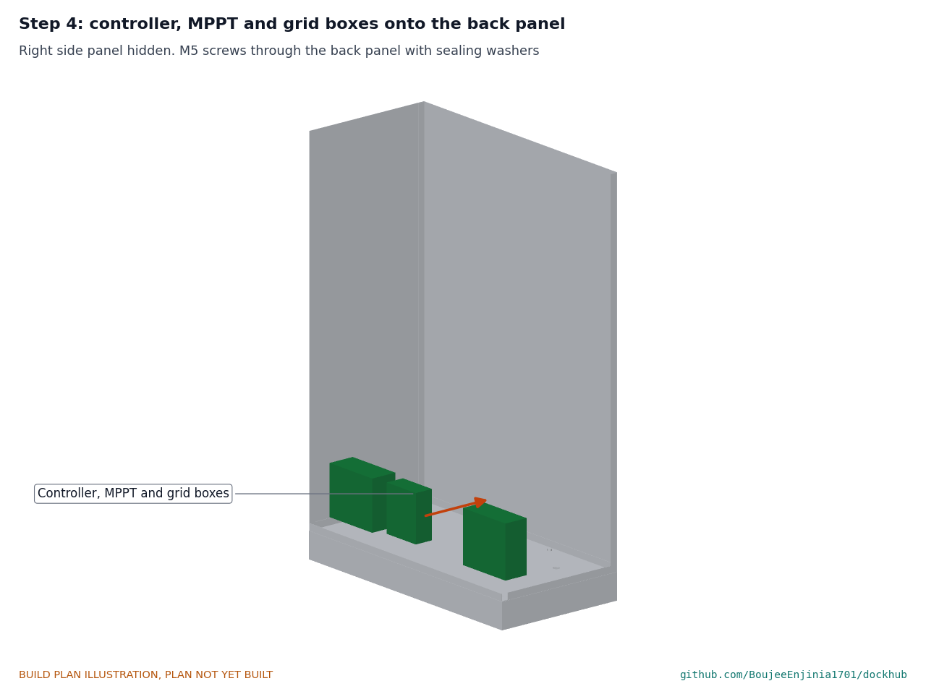
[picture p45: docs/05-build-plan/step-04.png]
Step 4


Hold each box against the back panel, mark its fixing holes through it, drill, and fit M5 screws with sealing washers. The controller goes from 450 to 230 mm left of centre, the MPPT controller from 190 to 40 mm left of centre and the grid box from 230 to 450 mm right of centre, all from 150 mm above the ground. **Hold point:** the grid box is connected only by the electrician (S2).

### Step 5: aerosol suppression unit

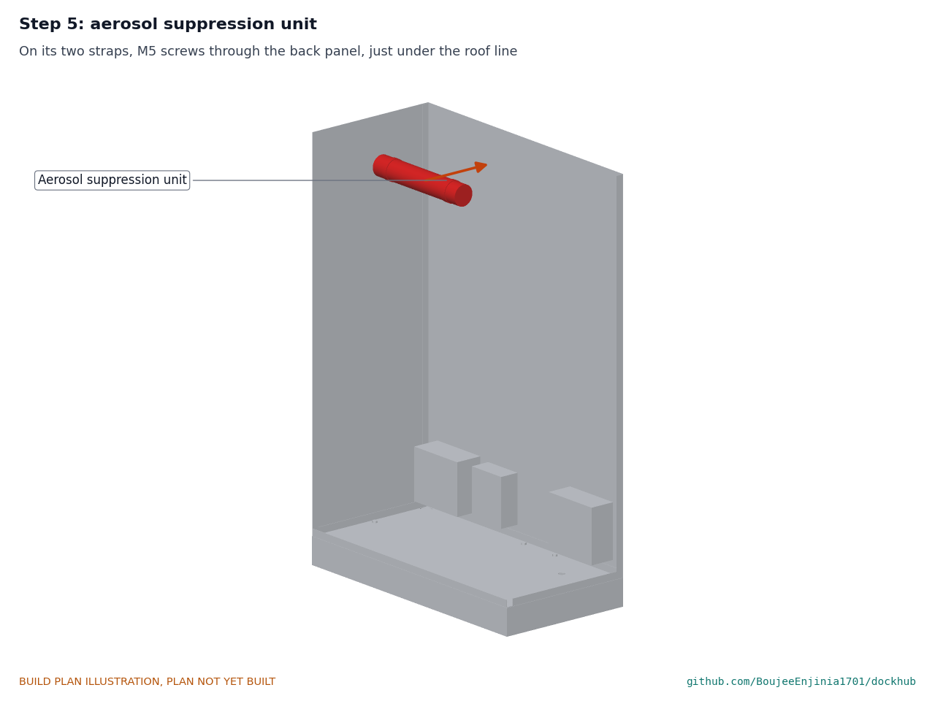
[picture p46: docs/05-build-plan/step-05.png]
Step 5


Fit the unit on its two straps, two M5 screws each through the back panel, 1,400 to 1,440 mm above the ground, 60 mm left of centre. Leave its trigger disconnected until S5.

### Step 6: charger shelf

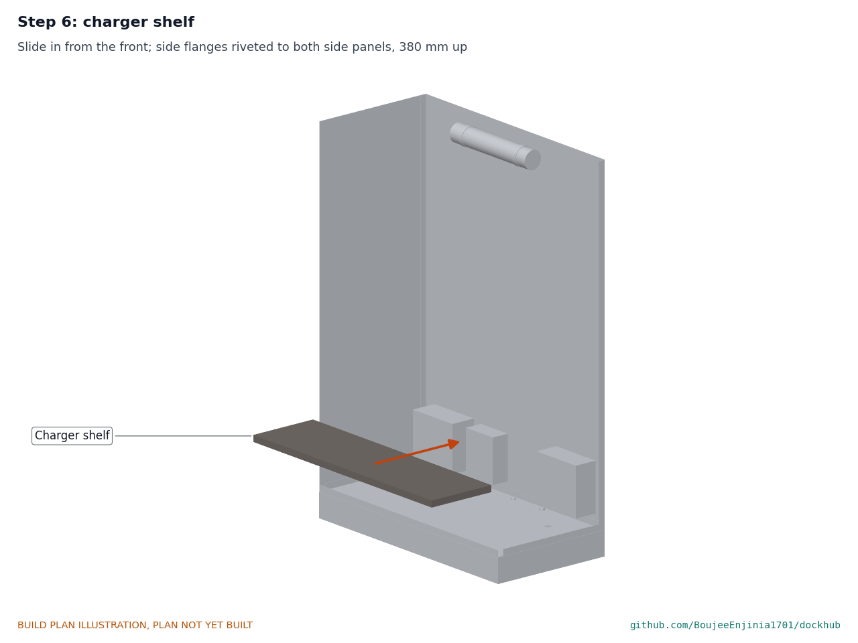
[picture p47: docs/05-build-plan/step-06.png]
Step 6


Slide the shelf in from the front, top face 380 mm above the ground, and rivet its side flanges to the side panels.

### Step 7: chargers onto the shelf

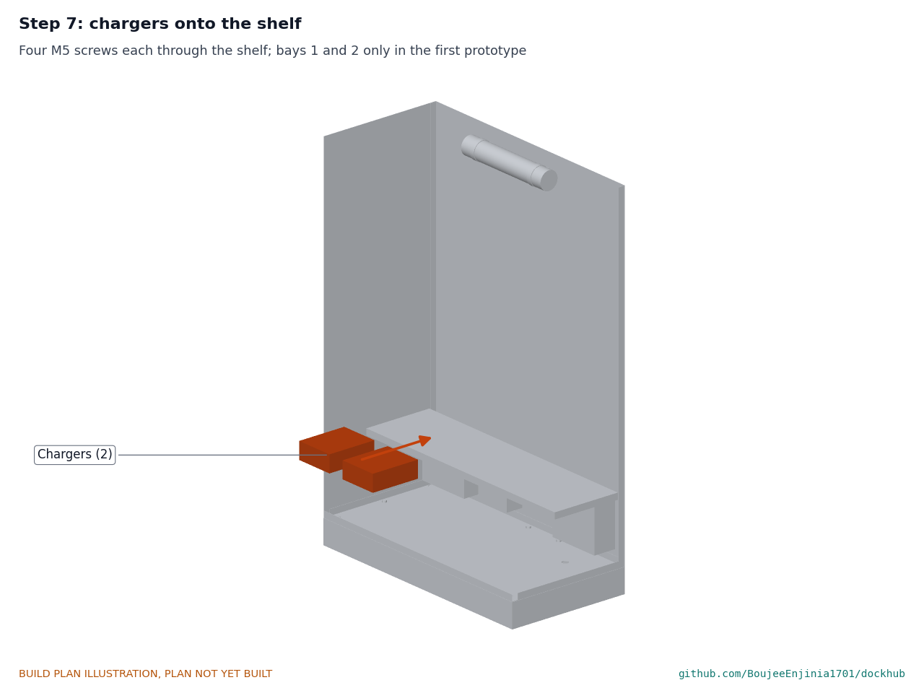
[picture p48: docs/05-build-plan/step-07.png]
Step 7


Stand each charger on the shelf, mark through its feet, drill and fit four M5 screws. Leave all mains and DC leads unconnected.

### Step 8: bay deck

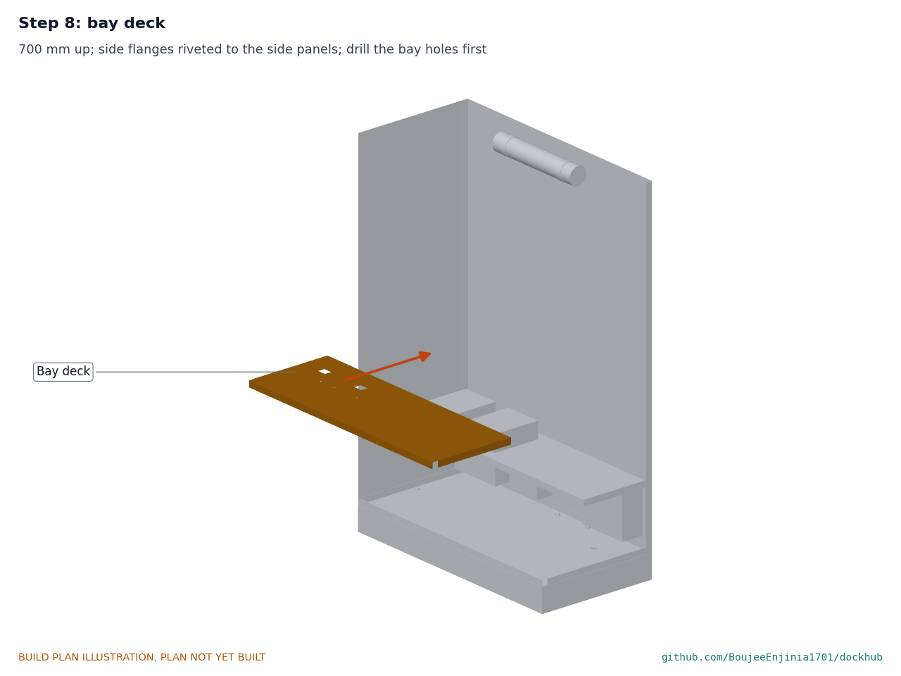
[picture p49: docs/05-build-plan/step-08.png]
Step 8


Drill the bay holes first (section 3.6). Slide the deck in, top face 700 mm above the ground, and rivet its side flanges to the side panels.

### Step 9: plenum wall

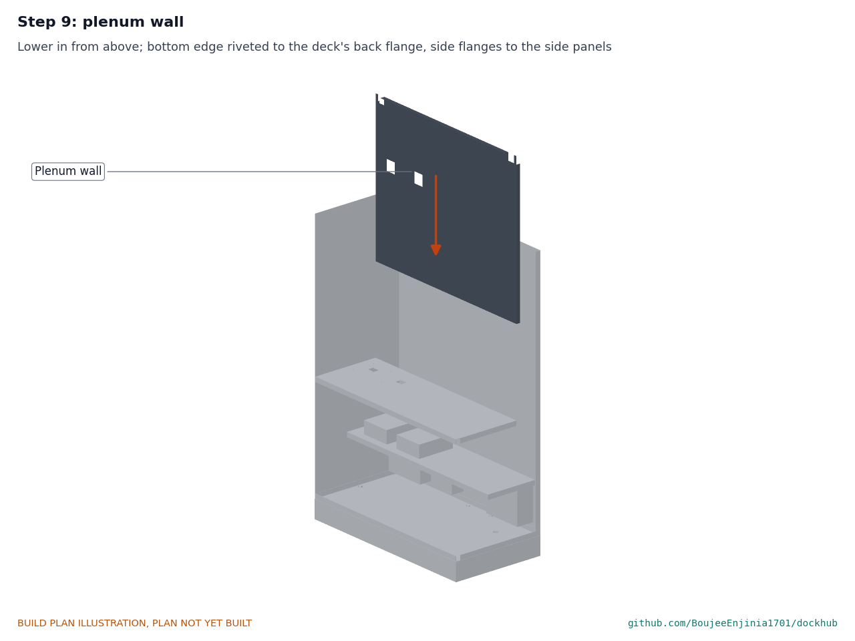
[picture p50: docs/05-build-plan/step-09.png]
Step 9


Lower the wall in from above behind the deck, its bottom edge overlapping the deck's back flange. Rivet it to the deck flange and its side flanges to the side panels.

### Step 10: bay liners

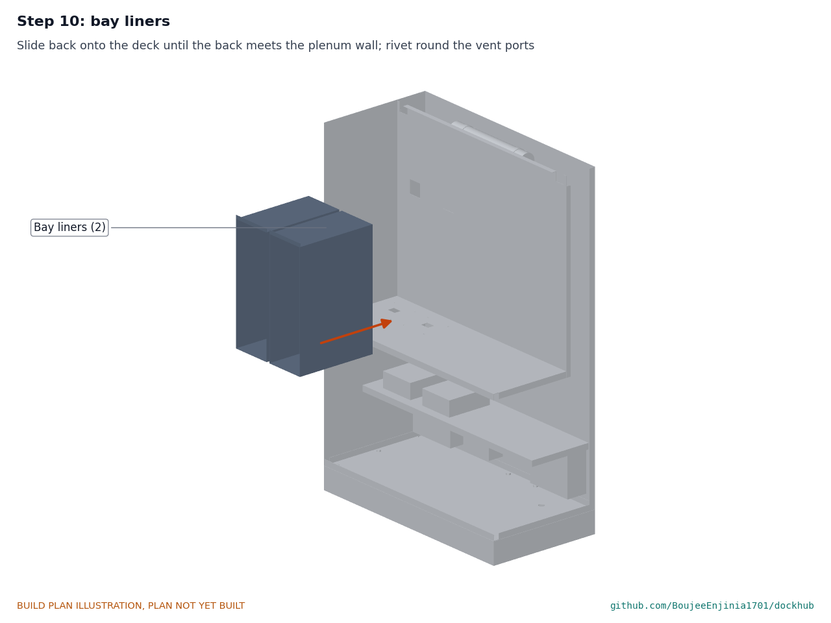
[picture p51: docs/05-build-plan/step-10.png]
Step 10


Slide each liner back onto the deck until its back touches the plenum wall, with the ports lined up. Rivet the back to the plenum wall round the port from inside the liner.

### Step 11: cradles, receptacles and catch brackets

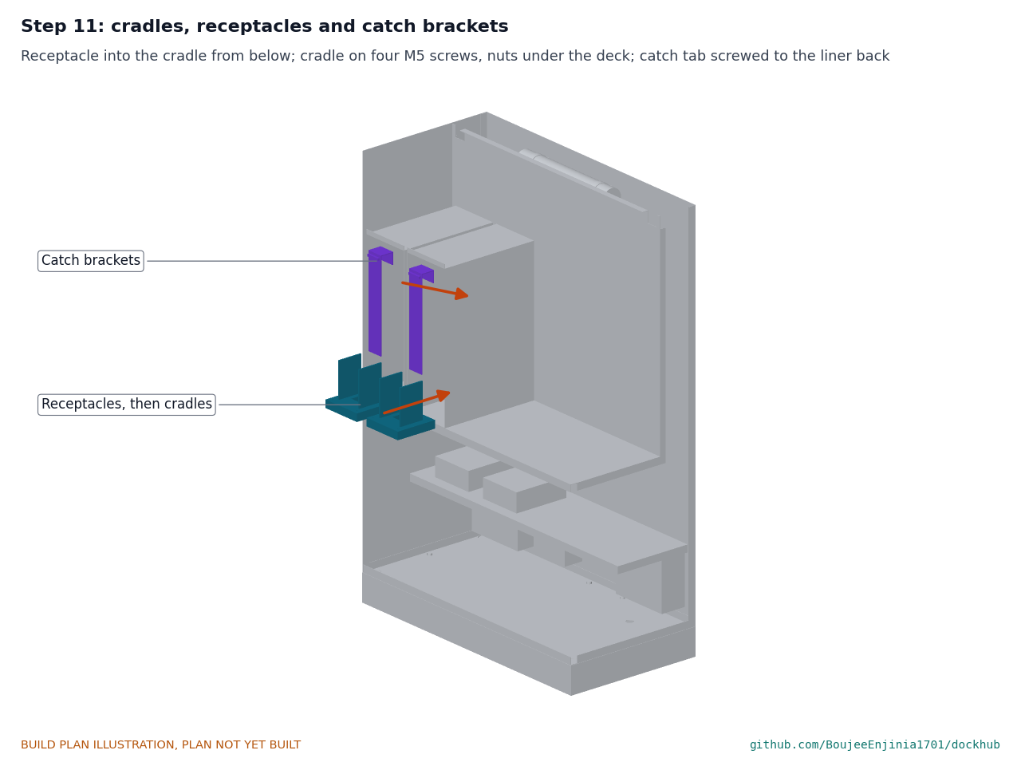
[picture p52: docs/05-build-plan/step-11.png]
Step 11


With its receptacle already screwed in from below, set each cradle in its liner, feed the receptacle lead down through the cable holes, and fit four M5 screws through liner floor and deck with nuts under the deck. Stand the catch bracket in the cradle's slot and screw its tab to the liner back wall with two M4 screws.

### Step 12: solenoid locks

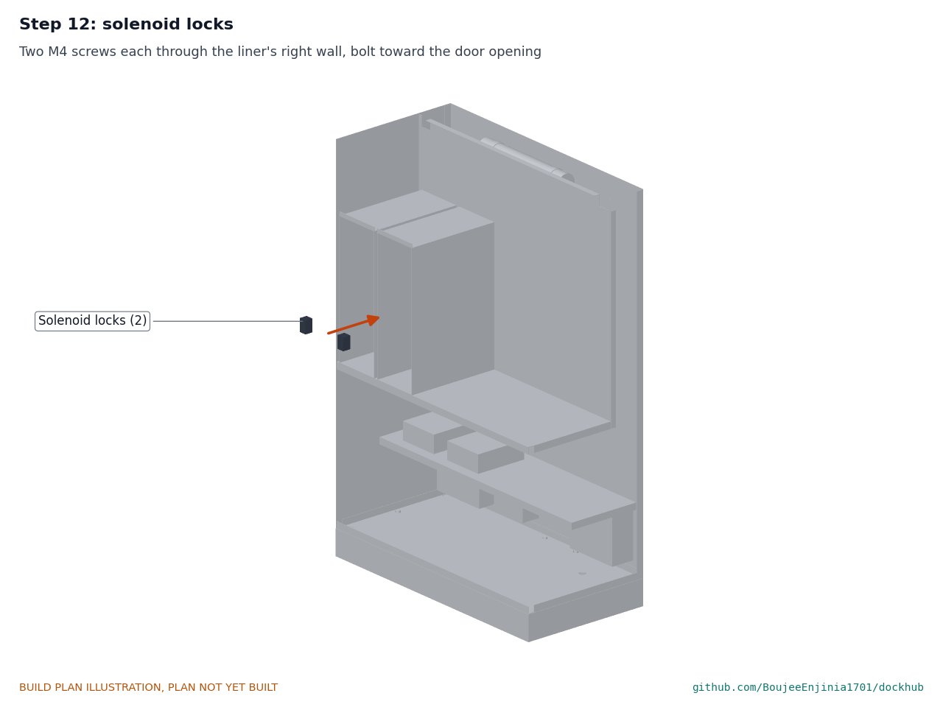
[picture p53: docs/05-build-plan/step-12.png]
Step 12


Fit each lock inside its liner against the right wall, two M4 screws through the wall, bolt toward the door opening.

### Step 13: front panel

Step 13

Offer the front panel up with its side flanges inside the side panels. Rivet through the side panels, then from the front into the deck's front flange, the liners' top flanges and the floor flange.

### Step 14: build the roof sub-assembly

Step 14

Lay the roof upside down on a padded bench. Set the beams with their cleats on the post lines and hold each with two of its post bolts, loosely. Fit the two fans on M4 screws through 4 mm spacers, blowing up through the holes, and the detector between them.

### Step 15: roof onto the cabinet

Step 15

Turn the roof over and lower it in from above, the beams passing through the plenum wall notches. Rivet its flanges to the walls with mastic in the joint, and rivet the plenum wall's top flange to it. Fit the cleat bolts from outside through the front and back panels and roof flanges into the welded nuts, tight. Seal the notches.

### Step 16: vent hood

Step 16

Set the hood over both fan holes, slots to the back, and rivet and seal its flanges to the roof.

### Step 17: bay doors and blank plates

Step 17

Stick the gasket round each fitted opening. Rivet each hinge to the panel, then to the door, so the tongue enters the lock. Fit rivet nuts and the two blank plates over bays 3 and 4 on M5 security screws.

### Step 18: access panel

Step 18

Feed the reader and display leads through the cut-out and fix the bezel over it with security screws into rivet nuts.

### Step 19: service door

Step 19

Stick the gasket round the opening, rivet the hinge to panel and door, and fit the cam lock and the filter pad.

### Step 20: canopy posts

Step 20

Seen with the cabinet complete. Set each post's base plate on the roof over its beam, outer end flush with the roof edge, and replace the two loose bolts with the M10 post bolts through plate, roof and beam, sealing washers under the plate, nyloc nuts under the beam, tight. **Hold point:** S6 before the rails go on.

### Step 21: canopy rails

Step 21

Set each rail on its two cap plates, high end to the street, and fit two M8 bolts at each post. Check both rails lie in one plane before tightening.

### Step 22: solar panel

Step 22

Two people on stable platforms. Lay the panel on the rails, high edge to the street, and fit the four end clamps. Bring the panel cable down through the roof gland to the MPPT controller, unconnected. **Hold point:** S7.

## 5. First checks

These are the checks a TRL 4 test report would record; this plan only lists them. Requirement numbers are those of DKH-REQ-001.

*Table 2. First checks.*

| Check | Requirement | How | Pass when |
| --- | --- | --- | --- |
| Reach heights | R11 | Tape measure from the ground | Door handles, reader and pack handles all between 0.38 and 1.22 m (0.73 to 1.10 m expected) |
| Gloved swap | R1, R11 | A pack dummy of the SwapCell size and mass, returned and lifted out by a person in work gloves | Pack goes in and out without touching the door opening; under 60 s from tap to closed door |
| Door seal and lock | R9, R10 | Close each door; pull hard with the lock unpowered | Gasket evenly squeezed all round; door stays shut; switch reads closed |
| Receptacle alignment | R2 | Pack dummy with a plug of the interface size dropped in each bay | Plug enters the well without touching its sides; catch 1 mm over the pawl |
| Mains installation | R5 | Electrician's inspection and tests to local code | RCD trips within its rated time; earth continuity to every metal part; isolator locks off |
| Charge with a pack | R3 | One healthy pack, bay 1, attended | Charging starts only after the CAN check; 20 to 80 % in about 1.2 h |
| Shutdown chain | R7 | Warm the bay's receptacle sensor with a heat gun to 60 °C | Contactor opens within 1 s of detection; buzzer, light and remote alert; door stays locked |
| Vent path | R7 | Smoke pencil at a bay's vent port with the fans on | Smoke leaves through the hood's back slots only |
| Canopy height | R13 | Measure from the ground | Lowest canopy point over the walkway 2.1 m or more (2.17 m expected) |
| Mass | | Weigh on a crane scale | About 217 kg without packs |
| Part swap | R14 | Time a technician changing a charger and a lock with hand tools | 15 minutes or less each |

## 6. Safety stops

Stop at each point. Carry on only when everything listed is true.

- **S1. Before any cutting or welding.** Zinc ground off weld areas; welding with extraction or outdoors; a fire extinguisher at hand; cut-resistant gloves for sheet.
- **S2. Before the grid box is connected.** A qualified electrician designs and makes the supply connection to local code: RCD, a breaker per charger, surge protection, lockable isolator, and every metal part bonded to earth. Mains and the 54.6 V DC side are kept apart and labelled.
- **S3. Before mains is switched on.** The electrician's tests pass; every DC line has its 60 V DC fuse fitted; all doors and the service door are closed; the isolator is locked off whenever anyone works inside.
- **S4. Before any pack enters the workshop.** The cabinet stands on a non-combustible floor, outdoors or in a fire-rated space, with a lithium-rated extinguisher and a bucket of sand within reach. Every pack has been checked by the SwapCell procedure: no damage, swelling or water, and it answers on CAN.
- **S5. Before the first charge.** The shutdown chain check of section 5 has passed with no pack in the cabinet; the aerosol unit is connected; the first charge is attended the whole time and stopped if any pack passes 45 °C. Never force-charge a pack that does not answer.
- **S6. Before the canopy rails go on.** Every post bolt tight; the cabinet cannot tip: it stands on a level floor and, if outdoors, is anchored or held by ballast and straps.
- **S7. Before the cabinet goes outdoors or to a site.** The first site is private property with an existing single-phase circuit and a responsible host, not a public sidewalk. The cabinet stands on the cast pad of section 9, at least 7 days old, held by the four M12 wedge anchors, each rated for at least 3.8 kN design tension and tightened to the maker's torque; the site is away from building doors and windows with the hood slots facing away from people; a clear walkway beside it. Without the anchors and the pad a 30 m/s gust tips the cabinet with its canopy.

## 7. Tools, skills and workspace

**Tools.** Access to a sheet metal shop with a laser or punch and a folder for 1,400 mm, or a 1.5 m hand folder; MIG welder and angle grinder (or a fabricator for the plinth and posts); drill press and hand drills, drills 3 to 14 mm, step drill to 40 mm, 110 mm hole saw; blind rivet tool and rivet nut tool; M3 heat-set insert tool; files and deburring tool; tape measure, steel rule, square, spirit level and string line; spanners and sockets 8 to 19 mm with an extension long enough to reach the anchor nuts through the floor; torque wrench; 3D printer with a bed of at least 160 x 160 mm that prints a flame-retardant grade; two trestles, timber bearers, a pallet truck or engine crane; two stable work platforms for the canopy; multimeter.

**Skills.** Sheet metal marking out, drilling and riveting; MIG welding of channel, tube and plate (or a fabricator); safe lifting. All mains work is done or checked by a qualified electrician: it is not part of the maker's work. Care with lithium-ion packs to the SwapCell procedure.

**Workspace.** A floor area about 3 x 3 m with 3 m of headroom for the canopy, non-combustible and level; a separate welding and grinding area; the pack area of S4.

**Personal protective equipment.** Safety glasses, cut-resistant gloves for sheet, welding helmet, gloves and jacket, hearing protection for grinding, safety boots; a harness or guard rail if the platforms for the canopy are high enough to need one.

## 8. Where the numbers come from

- Model and fit checks: `cad/src/model.py` (`python cad/src/model.py --check`: no overlaps, 60 joints that must touch all touch; the site pad and anchors and the trial floor trays also fit, and a socket reaches every anchor nut); STEP and STL exports in `cad/step/` and `cad/stl/`.
- Pictures: `cad/src/build_plan_media.py`, using `.kit/build_views.py`; written to `docs/05-build-plan/` and `cad/drawings/DKH-DWG-101` to `DKH-DWG-120`.
- General arrangement: `cad/drawings/DKH-DWG-001.pdf`, Rev P3.
- Calculations: `docs/04-calcs/01-sizing.md` (DKH-CAL-001 v0.6) and `docs/04-calcs/sizing.py`: mass (section 10), wind and anchors (section 11), cost (section 12), reach and canopy heights (section 9).
- Bill of materials: `bom/bom.csv`.
- Decisions: `docs/decisions/0003-design-for-construction.md` (DKH-DDR-003), with DKH-DDR-001 and DKH-DDR-002; open items in `docs/06-design-decisions.md` (DKH-DEC-001).
- Requirements: `docs/03-requirements.md` (DKH-REQ-001 v0.8).

## 9. Site pad and anchors, and the trial floor tray

### 9.1 Site pad and anchors

Figure 30. Making sketch of the site pad and anchors

*Figure 30. Site pad and anchors making sketch (DKH-DWG-120).*

**What it is and what it is made from.** The first site is private ground, so the cabinet stands on its own cast pad rather than on whatever the host's ground happens to be. The pad is reinforced concrete, 1,400 x 1,100 x 300 mm, top level with the ground, on 100 mm of rammed gravel; it weighs about 1,110 kg. Four M12 x 160 mm stainless steel wedge anchors hold the plinth to it. With the cabinet, the pad resists tipping at a 30 m/s gust with the safety factors of the calculation note (section 11).

**How to make it.**

1. Dig a hole 1,600 x 1,300 mm and 400 mm deep; ram in 100 mm of gravel.
2. Set formwork 1,400 x 1,100 mm inside, its top level with the ground and checked with a spirit level.
3. Tie a mesh of 10 mm bars at 200 mm both ways near the bottom and another near the top, each with 40 mm of cover, on plastic chairs.
4. Cast about 0.46 m³ of concrete from 28 bags of 36 kg premix, rodded or vibrated, and float the top flat. Keep it damp and leave it for at least 7 days.
5. Set the cabinet centred on the pad. Through each anchor hole in the plinth, drill 12 mm into the concrete, 115 mm deep, and blow the hole clean.
6. Drive each anchor to 100 mm embedment, fit the washer and the tamper-resistant nut inside the channel, and tighten to the anchor maker's torque with a socket through the floor. Cap the floor holes.

**How it fits the parts next to it.** The anchors are 225 mm from the pad's ends and 330 mm from its front and back edges, which keeps them well clear of the concrete edges. Grid power comes in through the cable gland in the floor from the host's existing circuit, laid by the electrician.

**Check before moving on.** The pad is level within 3 mm; each anchor reaches its torque without spinning; safety stop S7 is met. If an engineer confirms that the host already has a slab that does the same job, the pad can be left out.

### 9.2 Trial option: vermiculite floor tray

Figure 31. Making sketch of the vermiculite floor tray

*Figure 31. Vermiculite floor tray making sketch (DKH-DWG-119). Trial option only.*

**What it is and what it is made from.** The first prototype keeps plain bay floors and the aerosol unit. For the later propagation trial, each bay can instead have a shallow stainless steel tray of exfoliated vermiculite on its floor, in front of the cradle, so that the trial can compare the two. It is 1 mm stainless sheet, 175 x 168 x 20 mm, holding about 0.5 L of vermiculite.

**How to make it.**

1. Cut a blank 215 x 208 mm and fold 20 mm sides up all round; rivet the corner tabs.
2. Drill two 4.1 mm holes in the bottom on the centre line, 40 mm in from the front and back walls.
3. Set the tray on the bay liner's floor, 2 mm behind the front panel and 3 mm in front of the cradle, and rivet it through the liner floor with two 4 mm stainless blind rivets.
4. Fill it with vermiculite to 2 mm below the rim.

**How it fits the parts next to it.** The rim stands 16 mm above the bottom edge of the door opening and 10 mm below the pack's connector face, so a pack still slides in over it and drops into the cradle.

**Check before moving on.** A pack dummy goes in and out without touching the tray or spilling the fill.

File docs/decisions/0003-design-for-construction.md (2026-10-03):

---
doc_id: DKH-DDR-003
title: DockHub design for construction
project: DockHub
doc_type: Design decision record
version: "0.4"
status: Draft
date: '2026-10-02'
author: Amish Chadha
license: CERN-OHL-S-2.0
revisions:
- version: "0.1"
  date: '2026-10-01'
  author: Amish Chadha
  change: Changes that make the concept physically buildable, with the reason for each; made under Amish's 2026-09-30 instruction to make the design physically buildable; open for his review
- version: "0.2"
  date: '2026-10-01'
  author: Amish Chadha
  change: Budget treated as a value-engineering target
- version: "0.3"
  date: '2026-10-02'
  author: Amish Chadha
  change: "Accepted by Amish, including the recommendation for A2"
- version: "0.4"
  date: '2026-10-02'
  author: Amish Chadha
  change: "Consequences updated: appearance model brought to the constructable design and render scenes exported; socket holes added to the plinth top flange"
---

# 0003: Design for construction

- **Date:** 2026-10-01
- **Status:** accepted. Amish, 2026-10-02: "i approve your recommendations for all 555 open decisions." This covers every change in Tables 1 and 2 and the recommendation for A2 in Table 3, which is now decided as recommended and recorded in the design decisions register (DKH-DEC-001).

## Context

On 2026-09-30 Amish asked for every repo's build plan to show how each component is made and how it fits the next, with pictures, and wrote: "If you are realising that the design cannot be built as per concept - fix the design assumptions to match and be physically feasible as you draw the illustrations." The TRL 3 model of DockHub (DKH-DDR-001, DKH-DDR-002) showed what the station does with correct proportions, but it was a massing model: the cabinet was one closed box, many parts floated in the air with no fixing, some overlapped inside one part where the clash check could not see them, and some joints could not be reached to assemble.

The changes keep what DockHub does: the same 1,000 x 500 mm footprint and 1,500 mm cabinet, four bays at 196 mm pitch with bays 1 and 2 fitted, the SwapCell interface v0.3 cradle, receptacle and catch, the same pack, charger, controller, access, grid, fire and canopy parts, the same reach heights and the same canopy panel position and tilt. Nothing here changes the pitch or the safety case. Every change is in `cad/src/model.py`, which now models 41 components one by one and runs a fit check (`python cad/src/model.py --check`): no two components overlap, in either the two-bay or the four-bay fit, and all 60 joints that must touch do touch.

## Decision

*Table 1. Changes made to the model, the BOM and the calculations.*

| # | Problem in the concept | Change made | Why this way |
| --- | --- | --- | --- |
| P1 | The cabinet body was one hollow box with no joints, so it could not be made from sheet. | Six 1.5 mm galvanized panels: a laser-cut front panel and a back panel, each with 25 mm side flanges folded inward; two flat side panels outside those flanges; a floor pan with 25 mm flanges up and a roof with 40 mm flanges down, both inside the walls with corner reliefs. All joints are 4 mm blind rivets at about 100 mm pitch. | A sheet metal shop can cut and fold every panel, and two people can rivet them together from outside. No part depends on welding thin galvanized sheet. |
| P2 | The canopy posts stood on the 1.5 mm roof sheet. BOM line 1 named a roof frame but the model had none. Each front post pulls up with about 1.25 kN at a 30 m/s gust. | Two 40 x 40 x 4 mm angle beams, 494 mm long, under the roof on the post lines (460 mm each side of the centre). Each end carries a cleat of the same angle bolted to the beam with two M8 bolts and carrying two welded M8 nuts; bolts come in from outside through the front (or back) panel and the roof flange into those nuts. The posts bolt through the roof into the beams with two M10 bolts each. | Takes the uplift straight into the front and back panels and down to the plinth. Welded nuts mean no bolt has to be reached inside the closed cabinet. |
| P3 | The posts stopped 5 mm below the rails, the rails 2 mm below the panel, and nothing held the panel. | Posts welded to 50 x 100 x 8 mm base plates and to 50 x 70 x 6 mm cap plates cut to the 10° slope; rails sit on the cap plates on two M8 bolts each; rails lengthened from 1,054 to 1,174 mm so that four solar end clamps hold the panel frame's front and back edges. | Every canopy joint touches and is bolted. End clamps hold a bought panel without drilling its frame. The lowest canopy point over the walkway moves from 2.18 to 2.17 m (R13 still met). |
| P4 | The plenum wall was a 10 mm slab with no openings, so the liners' vent ports opened onto a solid wall. | A 1.5 mm folded wall with a 60 x 60 mm port behind each fitted bay, riveted to the bay deck's back flange, the side panels and the roof; its top corners are notched for the roof beams and sealed with fire-rated sealant. | Gas from a bay now reaches the plenum. Plenum section 1,366 cm². |
| P5 | Two 120 mm fans were drawn under an 80 mm deep louver with no hole in the roof; the louver was a solid block with slots cut through it. | Two 110 mm holes in the roof; square 120 mm fans hung under it on 4 mm spacers; a folded vent hood 850 x 133 x 70 mm over both holes, with twelve 50 x 40 mm slots in its back face, a rain lip, and flanges riveted and sealed to the roof. | Air and gas now have a path out, still to the back and up, away from the rider. Slot area 240 cm² (was 158 cm² of louver); air speed through it about 1.0 m/s [DKH-CAL-001 section 8]. |
| P6 | Bay doors 172 mm wide were hung 2 mm in front of 172 mm openings with no hinge, no gasket land and no lock. | Door openings narrowed to 150 mm. Doors 172 x 526 x 2 mm overlap the opening by 11 mm each side and 8 mm top and bottom, close on a 7 x 3 mm EPDM gasket, hang on a stainless piano hinge along the left edge, and carry a lock tongue that enters a 12 V solenoid lock screwed to the liner's right wall. | Leaves 24 mm between doors for the hinge knuckle and leaf. The pack (90 mm) still has 30 mm each side, and the handle top is 110 mm below the opening top. Reach heights are unchanged (R11). |
| P7 | The receptacle and the cradle occupied the same space (hidden because both were in one part); the side guides and catch post stood on nothing. | One printed cradle with its guides, a plug well on top and a receptacle pocket underneath; the receptacle screws into the pocket from below; the cradle stands on the liner floor on four M5 screws through liner floor and bay deck. The catch is on a folded 60 x 3 mm steel bracket that stands in a slot in the cradle and is screwed to the liner back wall. The cradle is printed in a flame-retardant (UL 94 V-0) filament. | Every part is held, and the receptacle sits where the pack's plug lands (interface v0.3 unchanged). A V-0 grade keeps the cradle from feeding a fire in the bay. |
| P8 | The bay liners, bay deck and charger rack floated with no fixing; the rack was a 10 mm plate. | Liners folded from 1.5 mm sheet with a 15 mm top flange riveted to the back of the front panel, the back riveted to the plenum wall round the port, the floor held by the cradle screws. Deck and charger shelf are 1.5 mm folded sheet with flanges riveted to the side panels and front panel. | Everything inside is fixed to the shell. The 16 mm gap between liners is kept. |
| P9 | The controller, MPPT and grid boxes floated 8 to 40 mm in front of the back panel; the aerosol unit and detector floated in the plenum. The grid box clashed with the new shelf flange. | The three boxes screw straight to the back panel with sealing washers; the grid box is 200 mm tall (was 210). The aerosol unit is held on its maker's two straps screwed to the back panel; the detector is screwed under the roof. | Every unit has a wall to fix to and none needs a new bracket. |
| P10 | The plinth was a solid 60 mm ring; the floor had no fixing to it; the anchor points were under the electrical boxes, where no tool could reach them once the cabinet was built. | A welded frame of 100 x 50 x 5 mm channel, flanges inward; eight M10 floor bolts through the floor pan and the top flange; anchors moved to 25 mm from the ends (still 30 mm from the front and back edges) and reached with a socket through four capped 40 mm holes in the floor. | A tool reaches every anchor nut with the cabinet complete. The wind calculation uses the front-to-back anchor spacing, which is unchanged. |
| P11 | The service opening was 960 mm wide, leaving no land for a hinge or gasket; the door floated; the filtered intake in BOM line 10 was not drawn. | Opening 900 x 500 mm; door 920 x 520 x 2 mm on a stainless piano hinge with a gasket and a cam lock whose arm turns behind the panel; a 400 x 80 mm intake slot with a filter pad behind it. | Room for hinge and gasket; the intake feeds the technical compartment and the plenum above it. |
| P12 | No order existed in which the roof frame could be bolted, because the cleat bolts would be inside a closed box. | Assembly order set in the build plan: shell, inside parts and front panel first; the roof is built as a sub-assembly with its beams, fans and detector and lowered in; cleat bolts go in from outside into welded nuts. | Every fixing can be reached when it is made. |

*Table 2. Knock-on changes.*

| Item | Change | Reason |
| --- | --- | --- |
| Mass | Two-bay prototype without packs 217 kg (was 205 kg); four bays with three packs 247 kg (was 234 kg) [DKH-CAL-001 section 10]. | Roof frame, post plates, hinges, clamps, catch brackets (9.6 kg) and the shelf and hood sheet. |
| Wind and anchors | Self-weight resists 0.53 kN·m (was 0.50) against 2.91 kN·m; front anchor design tension 3.79 kN (was 3.83) [section 11]. R15 stays at risk. | Higher mass. |
| Cost | BOM line 12 $60 to $70 (end clamps, post plates, bolts) and line 15 $30 to $35 (piano hinge): total $1,214 with two bays fitted (was $1,199) against the $1,200 value-engineering target (`budget_usd`), so R16 moves from at risk to **over the target by $14**. `budget_usd` is unchanged. All four bays $1,438. | Parts added for construction. Lines 1, 2, 3, 10, 14 and 16 were re-specified without a price change: the roof frame, door hinges, gaskets and fasteners were already in their scope. |
| Drawings | DKH-DWG-001 Rev P2; making sketches DKH-DWG-101 to 118 added. | Follows the model. |
| Documents | DKH-CAL-001 v0.4, DKH-PRC-001 v0.6, DKH-REQ-001 v0.6: mass, wind, vent path, canopy height, opening width, cost and R16 status updated; build plan DKH-BLD-001 and design decisions register DKH-DEC-001 added. | Follows the model. |
| Thermal, charging, throughput, grid, reach | Unchanged. | The cabinet, bays, packs and canopy keep their size and position. |

*Table 3. Item proposed for Amish, then accepted by Amish as recommended on 2026-10-02.*

| # | Question | Options | Recommendation |
| --- | --- | --- | --- |
| A2 | The bay doors now hang on piano hinges riveted to the outside of the front panel. A hinge pin on the outside can be attacked, which bears on R10 (security). | (a) stainless piano hinges with the pin ends peened over, as modelled; (b) concealed hinges inside the liner, which need a wider bay pitch or welded hinges. | (a) for the prototype; review after the first site visit. Accepted by Amish, 2026-10-02. |

## Consequences

- With the changes accepted and A2 decided on 2026-10-02, the bay doors keep their stainless piano hinges with peened pins for the prototype, to be reviewed after the first site visit; the renders are now to be regenerated to this design (DKH-DEC-001).
- `design_state: constructable` in `project.yaml`. The build plan DKH-BLD-001 shows every component and step in pictures generated from the model (`cad/src/build_plan_media.py`).
- Cost is reported against the value-engineering target: USD 1,200 (a hypothetical control target, not a limit) against an estimated USD 1,214 for the constructable design, USD 14 over; the register lists cost drivers and savings worth trying.
- Requirement status: two not met (R6, R9), one over its value-engineering target (R16), two at risk (R8, R15), two not verifiable at TRL 3 (R7, R14), nine met (DKH-CAL-001 v0.4).
- The appearance model `cad/src/product_model.py` was brought to the constructable design on 2026-10-02 (piano hinges, 150 mm door openings, vent hood, roof beams, post plates, rails and end clamps, all taken from `cad/src/model.py`) and the render scenes were exported; the photoreal renders (`media/render-*.png`), `media/card.png` and `media/social-preview.png` are re-rendered from them on Amish's Mac, where Blender is. The door windows stay in the renders only (decided 2026-10-02).
- Follow-up found on 2026-10-02: the plinth's top flange lay over the anchor holes, so a socket could not reach the anchor nuts as P10 intended. A 32 mm socket hole was added in the top flange over each anchor; `cad/src/model.py --check` now checks the socket path.
- The bought parts (chargers, boxes, locks, receptacle, fans, aerosol unit, panel) are chosen at TRL 4; their sizes and fixings must be checked against the model then (design decisions register, "To confirm when parts are bought").

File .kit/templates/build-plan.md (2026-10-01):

---
doc_id: PRJ-BLD-001
title: Project prototype build plan
project: Project name
doc_type: Build plan
version: "0.1"
status: Draft
date: YYYY-MM-DD
author: Amish Chadha
license: CERN-OHL-S-2.0
revisions:
  - version: "0.1"
    date: YYYY-MM-DD
    author: Amish Chadha
    change: First build plan; design made constructable
---

# Project prototype build plan

**Plan, not yet built.** How to build the first proof-of-concept prototype, component by component. Building and testing to it is TRL 4 work. Decisions still to be made are kept in the design decisions register (`docs/06-design-decisions.md`), not here.

## 1. What you are building

Every component, pulled apart and numbered in build order

One short paragraph: what the prototype is, how many components, which are made and which are bought, and the main ways they are made.

## 2. What changed to make it buildable

| Component | The concept had | The buildable design has | Why |
| --- | --- | --- | --- |

## 3. Making the components

### 3.1 Component name

Making sketch

**What it is and what it is made from.**

**How to make it.**

1. Mark out ...
2. Cut ...

**How it fits the parts next to it.**

Close-up of the joint

**Check before moving on.**

## 4. Putting it together

### Step 1: ...

Step 1

## 5. First checks

| Check | Requirement | How | Pass when |
| --- | --- | --- | --- |

## 6. Safety stops

## 7. Tools, skills and workspace

## 8. Where the numbers come from

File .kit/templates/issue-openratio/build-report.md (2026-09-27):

---
name: Build report
about: Tell us what happened when you built, printed or tested part of this design
title: "Build report: "
labels: build-report
---

This is a research and educational prototype, not a medical device. It is a TRL 3 concept and is not released for fabrication. If you build any part of it, you do so at your own risk. Reports help everyone.

**What you built** (part, sub-assembly or test)

**Materials, tools and settings**

**What worked**

**What did not work, with photos or measurements if you have them**

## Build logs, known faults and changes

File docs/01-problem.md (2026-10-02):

---
doc_id: DKH-PRB-001
title: DockHub problem statement
project: DockHub
doc_type: Problem statement
version: "0.5"
status: Draft
date: '2026-10-02'
author: Amish Chadha
license: CERN-OHL-S-2.0
revisions:
- version: "0.1"
  date: '2026-09-25'
  author: Amish Chadha
  change: Initial scaffold
- version: "0.2"
  date: '2026-09-25'
  author: Amish Chadha
  change: Populate to TRL 2 (problem, users, context, constraints, prior work)
- version: "0.3"
  date: '2026-09-25'
  author: Amish Chadha
  change: TRL 3. Budget scope (four-bay cabinet, two bays fitted) and SwapCell interface v0.3 per DKH-DDR-001; open questions updated from DKH-CAL-001
- version: "0.4"
  date: '2026-10-01'
  author: Amish Chadha
  change: Budget treated as a value-engineering target
- version: "0.5"
  date: '2026-10-02'
  author: Amish Chadha
  change: "First site, partner and pack ownership as decided on 2026-10-02 (DKH-DEC-001)"
---

# DockHub problem statement

Riders who earn a living on light electric vehicles have two poor ways to recharge: wait hours at a socket, or take the battery home and charge it overnight in a flat, hostel or shared room. The first costs working time; the second is a leading cause of lithium-ion battery fires in homes. A shared, monitored place to exchange a flat pack for a charged one would address both.

## The problem

Light electric vehicle packs take hours to charge. India's draft battery swapping policy notes that "regular charging takes at least 3 to 4 hours" for electric two- and three-wheelers, while a swap "is done in minutes" ([NITI Aayog, draft battery swapping policy, April 2022](https://www.niti.gov.in/sites/default/files/2022-04/20220420_Battery_Swapping_Policy_Draft_0.pdf)). A delivery rider on a single pack must either stop work for that time or carry a second pack and charge it wherever they sleep.

Charging at home is where the fire risk sits. The US Consumer Product Safety Commission found 227 micromobility battery incidents from 2019 to 2023, associated with 39 deaths and 181 injuries; 120 of those incidents happened during charging ([Federal Register, 24 June 2026](https://www.federalregister.gov/documents/2026/06/24/2026-12749/safety-standard-for-lithium-ion-batteries-used-in-micromobility-products-and-electrical-systems-of)). New York City recorded 268 lithium-ion battery fires and 18 deaths in 2023, and 277 fires in 2024 ([FDNY](https://www.nyc.gov/site/fdny/news/03-25/fdny-commissioner-robert-s-tucker-significant-progress-the-battle-against-lithium-ion)). London Fire Brigade attended a record 206 e-bike and e-scooter fires in 2025; each of the five people killed in such fires in London since 2023 did not own the e-bike involved ([London Fire Brigade](https://www.london-fire.gov.uk/news/2026-news/january/record-number-of-e-bike-and-e-scooter-fires-across-london-in-2025-as-brigade-calls-for-regulation-to-be-introdu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)). The people at risk include neighbors and family, not only riders.

Commercial swap networks exist, but each is closed: the pack, cabinet, protocol and data belong to one operator, and a rider or small fleet is locked into that operator's batteries. The portfolio's SwapCell project defines an open pack and interface. What is missing is an open, street-side cabinet that stores, charges, checks and hands out those packs, which a city, a cooperative of riders or a small fleet could build and run.

## Users and context

| User | Need | Context |
| --- | --- | --- |
| App-based delivery rider | A charged pack in under a minute, near the delivery zone, at any hour; no pack in the bedroom overnight | Dense city centers; long shifts, often evenings and weekends |
| Cargo trike and courier fleet operator | Predictable uptime without buying a second pack per vehicle; pack health data | Depots and curbside loading zones |
| Moto-taxi or e-scooter rider in emerging markets | Low-cost energy without owning the battery | Informal transport hubs, markets |
| City transport or fire safety department | Fewer home battery fires; a safe, visible alternative that uses little sidewalk | Sidewalks, plazas, parking lanes |
| Host (shop, restaurant, building owner) | Low-effort hosting with a clear electrical load and safety case | Shopfronts, parking areas with a power supply |
| Technician | Replace a charger, lock or bay in minutes; read pack logs | Field service with hand tools |

## Operating environment

- Outdoor, on a sidewalk or plaza, exposed to rain, dust, sun and road salt; ambient roughly -10 to 45 °C (14 to 113 °F).
- Unattended around the clock, in public, so exposed to vandalism and theft.
- Fed from a single-phase supply of the kind available at a shopfront or streetlight cabinet (120 V or 230 V).
- Used by people with gloves, in the dark, in a hurry, and with a range of languages and abilities.

## Constraints

- Garage-buildable prototype, a value-engineering target of about $1,200 USD in parts (a hypothetical control target, not a limit) for the four-bay cabinet with two bays fitted, excluding SwapCell packs; the estimated cost of the constructable design is $1,214 (DKH-DDR-001 item 1, adopted for TRL 3 and open for Amish's review).
- Built from folded sheet steel, off-the-shelf certified chargers and hobby-grade controllers; no custom mains electronics.
- Must build to SwapCell interface v0.3 (envelope, coded connector, latch class, CAN message set) without changing it; conflicts are raised with the SwapCell project.
- No cameras or microphones. The station records pack identity, energy and a rider token, not personal data beyond what access requires.
- Siting on public land needs permission from the city and the power utility; the prototype is for a private forecourt or a supervised pilot.

## Out of scope

- Payment processing and pricing (the concept provides an access token only).
- Charging of non-SwapCell batteries, or of whole vehicles.
- Cars, motorcycles or any vehicle needing packs larger than one SwapCell double pack.
- Fleet routing, rebalancing of packs between stations and a multi-station back end beyond a simple log export.

## Prior work

- Closed commercial swap networks prove the model at scale. Ampersand reports more than 10,000 electric motorcycles and 20,000 battery swaps a day in Rwanda and Kenya ([Ampersand](https://www.ampersand.energy/)). Swobbee runs 24/7 swap stations for delivery riders in Berlin and New York City ([Swobbee](https://www.swobbee.com/)). Gogoro operates a scooter swap network in Taiwan and has announced expansions to markets including Chile, Korea, Singapore and the Philippines ([Gogoro news](https://www.gogoro.com/news/)).
- India's draft policy asks for interoperable, BMS-enabled packs with remote monitoring and for open ecosystems that let "other market players" build compatible products ([NITI Aayog, 2022](https://www.niti.gov.in/sites/default/files/2022-04/20220420_Battery_Swapping_Policy_Draft_0.pdf)).
- SwapCell (portfolio) defines the pack, blind-mate connector, CAN heartbeat and in-pack state-of-health log that DockHub builds on. Its single-pack wall dock is the pattern for each DockHub bay.

## User research and co-design

This design is for communities the author is not part of, so requirements come from the people who will use it.

- [ ] Identify a local partner organization (Helpful Engineering network, NGO or university)
- [ ] Run co-design sessions with intended users; record who, where and what was learned
- [ ] Validate load, distance, terrain and cost assumptions in the field
- [ ] Revise requirements (REQ) from findings before freezing the design

## Open questions

- Which first site and partner? Decided by Amish, 2026-10-02 (DKH-DEC-001): a delivery-worker group in a high-income city, New York City first, with Los Deliveristas Unidos (Workers Justice Project) as the first candidate partner to approach, and the first pilot on private property with an existing single-phase circuit.
- Who owns the packs in circulation? Decided by Amish, 2026-10-02 (DKH-DEC-001): a station-owned pool exchanged one for one, to be confirmed in co-design.
- How far do riders travel in a shift, and how many swaps a day does one station need to serve, at what hours? The 20 swaps a day and the lunch and dinner peaks used in DKH-CAL-001 are assumptions to test.
- How long will a rider wait for a charged pack before leaving? DKH-CAL-001 assumes 15 min.
- How hot does the first pilot site get? The SwapCell pack does not charge above 45 °C, so in hot afternoons DockHub pauses charging (DKH-CAL-001 section 7). R9 now asks for full-rate charging up to about 30 °C ambient, so the first pilot site is chosen with summer highs near that (DKH-DEC-001).

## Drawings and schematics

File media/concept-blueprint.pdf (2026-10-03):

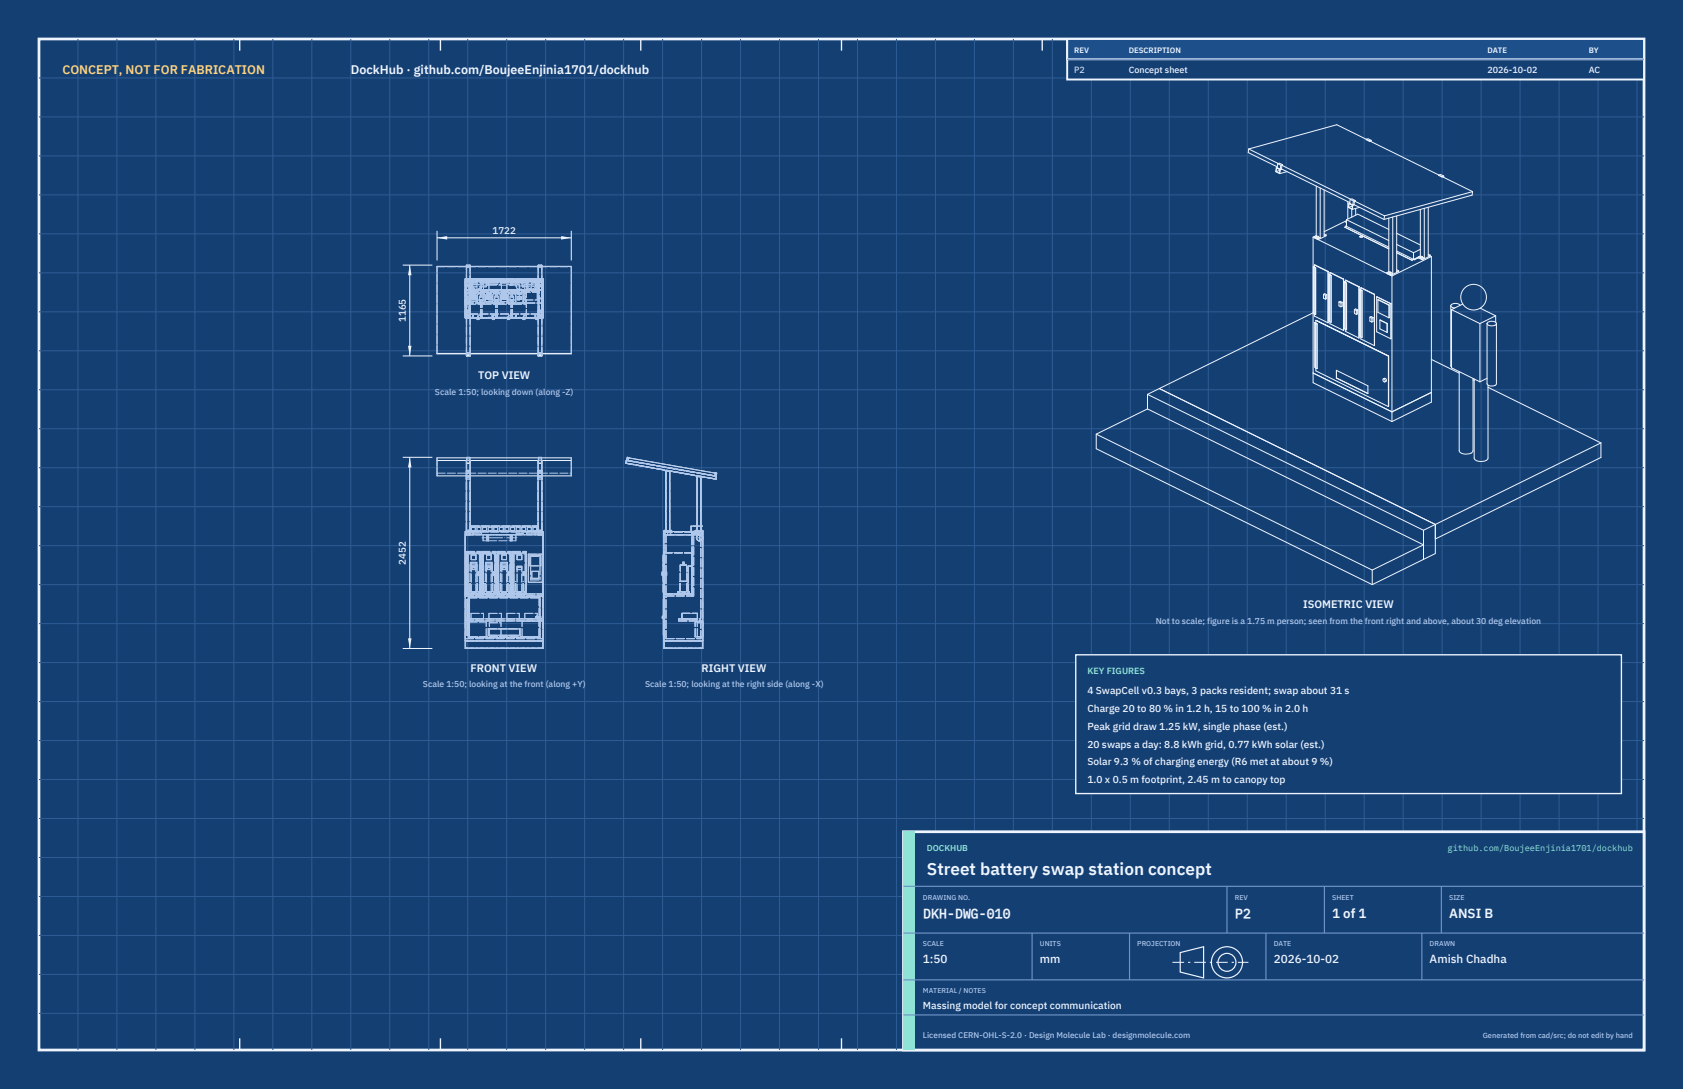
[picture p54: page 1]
CONCEPT, NOT FOR FABRICATION; DockHub · github.com/BoujeeEnjinia1701/dockhub; FRONT VIEW; TOP VIEW; RIGHT VIEW; ISOMETRIC VIEW; REV; DESCRIPTION; DATE; Concept sheet; DOCKHUB; github.com/BoujeeEnjinia1701/dockhub; DRAWING NO. DKH-DWG-010; REV P2; SHEET 1 of 1; SIZE ANSI B; SCALE 1:50; UNITS mm; PROJECTION; DRAWN Amish Chadha; Licensed CERN-OHL-S-2.0 · Design Molecule Lab · designmolecule.com; Generated from cad/src; do not edit by hand

Scale 1:50; looking down (along -Z)

Not to scale; figure is a 1.75 m person; seen from the front right and above, about 30 deg elevation

KEY FIGURES
4 SwapCell v0.3 bays, 3 packs resident; swap about 31 s
Charge 20 to 80 % in 1.2 h, 15 to 100 % in 2.0 h
Peak grid draw 1.25 kW, single phase (est.)
20 swaps a day: 8.8 kWh grid, 0.77 kWh solar (est.)
Solar 9.3 % of charging energy (R6 met at about 9 %)
1.0 x 0.5 m footprint, 2.45 m to canopy top

Scale 1:50; looking at the front (along +Y)

Scale 1:50; looking at the right side (along -X)

Street battery swap station concept

MATERIAL / NOTES
Massing model for concept communication

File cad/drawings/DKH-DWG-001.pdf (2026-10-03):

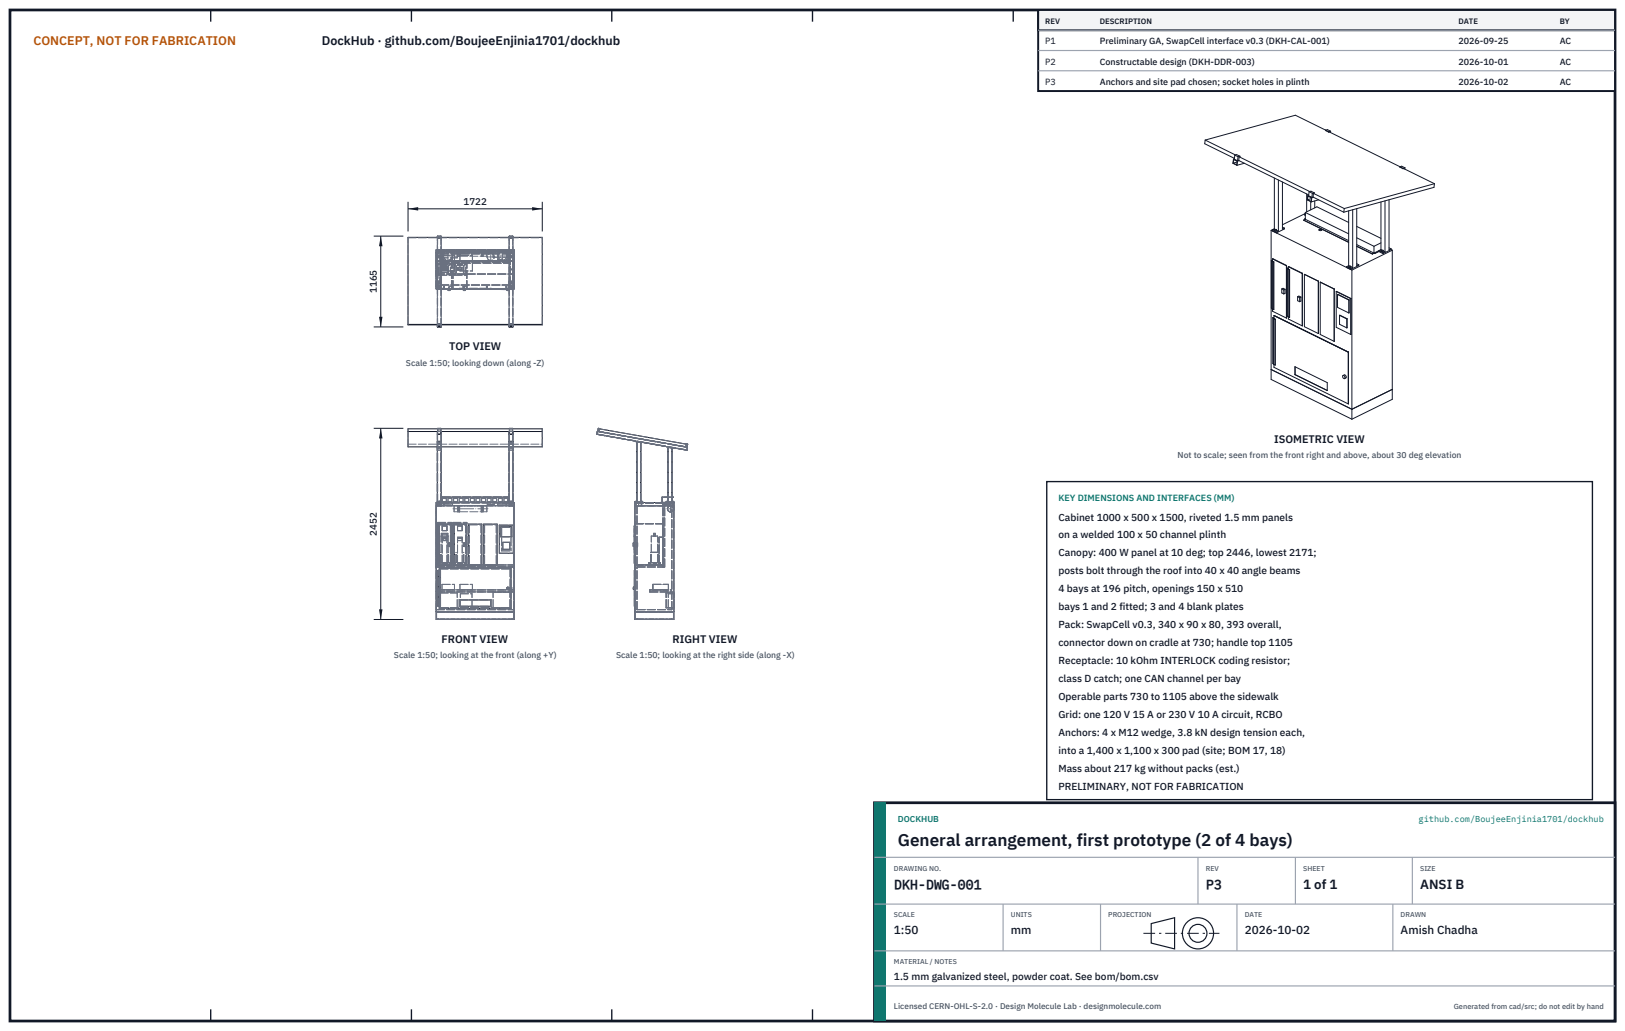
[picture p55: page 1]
CONCEPT, NOT FOR FABRICATION; DockHub · github.com/BoujeeEnjinia1701/dockhub; FRONT VIEW; TOP VIEW; RIGHT VIEW; ISOMETRIC VIEW; REV; DESCRIPTION; DATE; Preliminary GA, SwapCell interface v0.3 (DKH-CAL-001); Constructable design (DKH-DDR-003); Anchors and site pad chosen; socket holes in plinth; DOCKHUB; github.com/BoujeeEnjinia1701/dockhub; DRAWING NO. DKH-DWG-001; REV P3; SHEET 1 of 1; SIZE ANSI B; SCALE 1:50; UNITS mm; PROJECTION; DRAWN Amish Chadha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

Scale 1:50; looking down (along -Z)

Not to scale; seen from the front right and above, about 30 deg elevation

KEY DIMENSIONS AND INTERFACES (MM)
Cabinet 1000 x 500 x 1500, riveted 1.5 mm panels
on a welded 100 x 50 channel plinth
Canopy: 400 W panel at 10 deg; top 2446, lowest 2171;
posts bolt through the roof into 40 x 40 angle beams
4 bays at 196 pitch, openings 150 x 510
bays 1 and 2 fitted; 3 and 4 blank plates
Pack: SwapCell v0.3, 340 x 90 x 80, 393 overall,
connector down on cradle at 730; handle top 1105
Receptacle: 10 kOhm INTERLOCK coding resistor;
class D catch; one CAN channel per bay
Operable parts 730 to 1105 above the sidewalk
Grid: one 120 V 15 A or 230 V 10 A circuit, RCBO
Anchors: 4 x M12 wedge, 3.8 kN design tension each,
into a 1,400 x 1,100 x 300 pad (site; BOM 17, 18)
Mass about 217 kg without packs (est.)
PRELIMINARY, NOT FOR FABRICATION

Scale 1:50; looking at the front (along +Y)

Scale 1:50; looking at the right side (along -X)

General arrangement, first prototype (2 of 4 bays)

MATERIAL / NOTES
1.5 mm galvanized steel, powder coat. See bom/bom.csv

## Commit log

2026-09-25 Initial scaffold: standard open hardware layout, CERN-OHL-S v2 + MIT licenses
    Claude-Session: https://claude.ai/code/session_01XuhhSU4W6fYhgCfURbrkut
    [bom.csv]
2026-09-26 Populate to TRL 2: problem, requirements, precis, concept media, BOM and README use cases
    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
    [bom.csv]
2026-09-26 Advance to TRL 3: DDR-001, CAL-001 sizing, parametric model with STEP/STL, GA drawing, priced BOM; TRL 4 on hold
    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
    [bom.csv, dockhub-assembly-4-bays.step, dockhub-assembly-4-bays.stl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]
2026-09-26 Accept all recommendations (DDR-002), switch footer to designmolecule.com, add README write-up with new inspiration point
    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
    [dockhub-assembly-4-bays.step, dockhub-assembly.step, dockhub-bay.step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]
2026-09-27 Product appearance model and photoreal renders
    Adds cad/src/product_model.py (appearance model for renders only, all main
    dimensions from model.py) and Blender renders in media/render-*.png,
    captioned with the project, repository and viewing direction. README leads
    with the product render; trl stays 3.
    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
2026-10-01 Image quality pass: legible exploded views, flow diagrams and drawing sheets
    Kit 1.6.1 image layout: the parts list sits in its own column, number bubbles sit on visible parts and never overlap, small parts get a leader, pictures are cropped to the subject, flow labels keep numbers with their units, and sheet captions and the revision table no longer overprint. Concept images, blueprint and general arrangement sheet regenerated; repo-specific labels moved clear of other text and lines.
2026-10-01 Kit 1.7.0: constructable design, illustrated build plan and design decisions register
    The design is now constructable: every part can be made and fits its neighbours, with each change recorded in a Design for construction decision record (made under Amish's 2026-09-30 instruction; ope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
    [bom.csv, dockhub-assembly-4-bays.step, dockhub-assembly-4-bays.stl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]
2026-10-01 Budget treated as a value-engineering target
    Amish, 2026-10-01: the budget is a hypothetical control target that keeps the design on a value-engineering lens, not a spending limit. Documents now state the value-engineering target and the estima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
2026-10-02 Record Amish's approval of the open-decision recommendations
    Amish approved the recommendation on every open decision in the design decisions register ("i approve your recommendations for all 555 open decisions.", 2026-10-02). Each decision is moved to Decisio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
2026-10-03 Carry approved follow-ups into the design and redo photoreal renders
    Amish approved the follow-up actions from the open-decision sign-off ("APPROVED CHANGES, COMPLETE THESE", 2026-10-02), the design-for-construction change tables in ten repos, the last wave's open dec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
    [bom.csv, dockhub-assembly-4-bays.step, dockhub-assembly-4-bays.stl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]
2026-11-01 Kit 1.9.1 upgrade: pipeline documents and detailed CAD for every option
    STEM check with fixes under the standing instruction and an independent
    review, concept options scored against the user requirements, URS, PRS,
    RTM, REG, FEA, RSK, MKT, PLN and DDR, every option modelled at D3 with
    cad/fidelity.json passing, and the concept options picture rendered with
    Blender Cycles on Amish's Mac. Concept choices stay proposed, awaiting
    Amish.
    Claude-Session: https://claude.ai/code/session_01LppsZSzPTJWTBAV5wh1Goq

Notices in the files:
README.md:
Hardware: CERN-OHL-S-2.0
